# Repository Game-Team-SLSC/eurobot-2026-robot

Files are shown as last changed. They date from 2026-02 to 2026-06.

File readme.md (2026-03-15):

# Game Team's Eurobot 2026 Robot

## Hardware

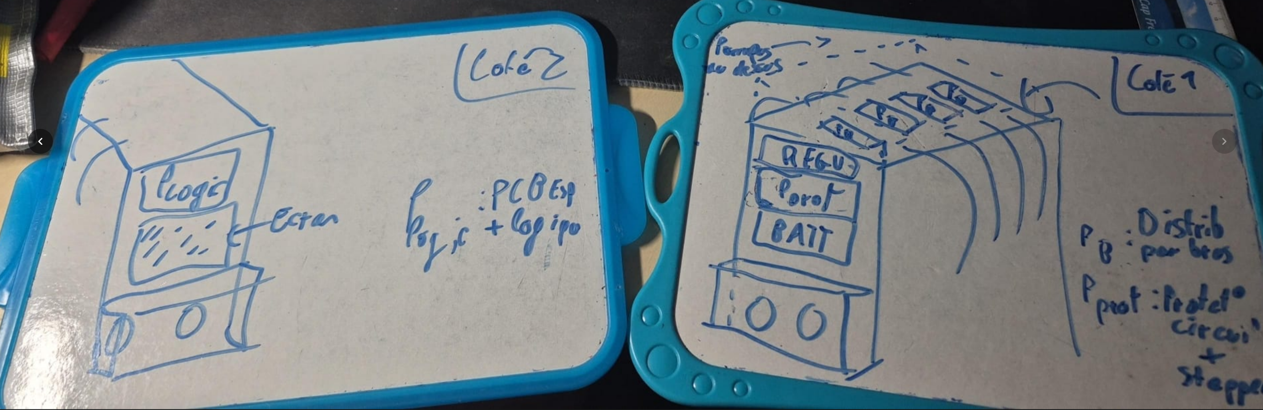
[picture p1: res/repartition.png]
Hardware


### Architecture Diagram

```mermaid
graph LR
    %% SOURCES EXTERNES
    Batt((Batterie LiPo 4S))
    BAU[Bouton AU]

    %% PCB 1: LOGIC BOARD
    subgraph LB [Logic Board]
        direction TB
        MCU[ESP32-S3]
        Radio[Module Radio]
        Screen[Écran LCD]
        MCU --- Radio
        MCU --- Screen
    end

    %% PCB 2: POWER BOARD
    subgraph PB [Power Board]
        direction TB
        Prot[Protection Batterie]
        subgraph Drivers [Drivers Steppers]
            D_4x[4x Drivers]
        end
    end

    %% PCB 3: SERVO REGULATORS (Considéré comme un bloc PCB)
    subgraph Regs [Regulators Board]
        direction TB
        SR[2x 200W Servos]
        PR[1x 200W Pump Reg]
        Fan[1x Ventilateur]
    end

    %% PCB 4: ARM BOARD
    subgraph AB [Arm Board]
        direction TB
        PCA[3x PCA9685]
        Mos[4x MOSFET Pumps]
    end

    %% MATÉRIEL PHYSIQUE (Hors PCB)
    subgraph Mecanique [Éléments Mécaniques]
        Mots[4x Steppers]
        CN[Chasse-Neige]
        Bras[Bras & Pompes]
    end

    %% CONNEXIONS INTER-PCB (Puissance)
    Batt == "16.8V" ==> PB
    PB == "16.8V" ==> LB
    PB == "16.8V" ==> Regs
    Regs == "7V / 12V" ==> AB
    BAU -.-> PB
    AB -- PWM -->Regs

    %% CONNEXIONS INTER-PCB (Signaux)
    LB -- "SPI" --> PB
    LB -- "I2C Main" --> AB
    PB -- "Télémétrie" --> LB

    %% CONNEXIONS PCB VERS MÉCANIQUE
    PB == "Phases" ==> Mots
    AB -- "PWM" --> CN
    AB -- "Faisceau" --> Bras

    %% STYLES
    style LB fill:#f3e5f5,stroke:#7b1fa2,stroke-width:2px
    style PB fill:#fff9c4,stroke:#fbc02d,stroke-width:2px
    style Regs fill:#e1f5fe,stroke:#0288d1,stroke-width:2px
    style AB fill:#e8f5e9,stroke:#2e7d32,stroke-width:2px
```

### Power PCB

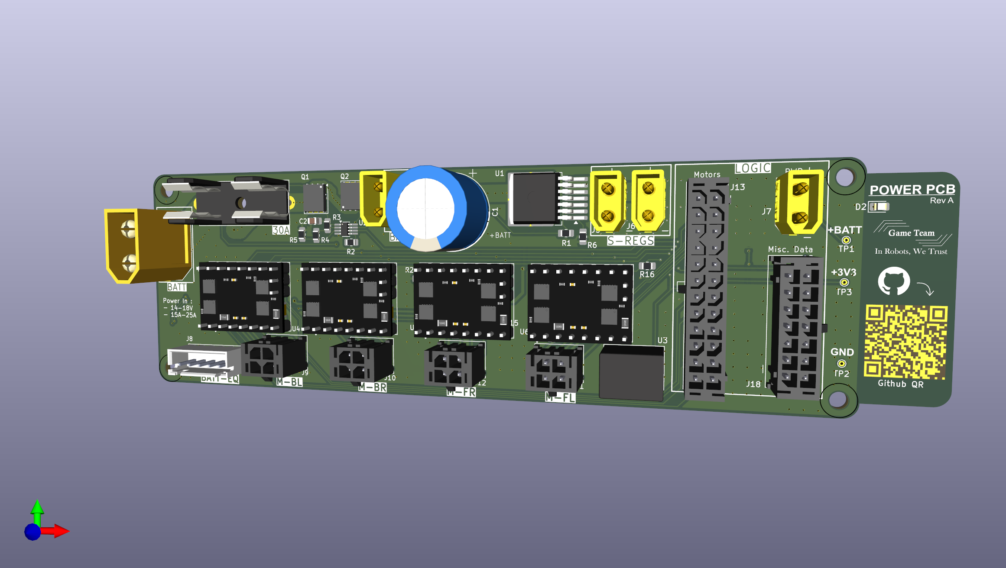
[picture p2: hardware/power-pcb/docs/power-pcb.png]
Power PCB


### Kinetic PCB

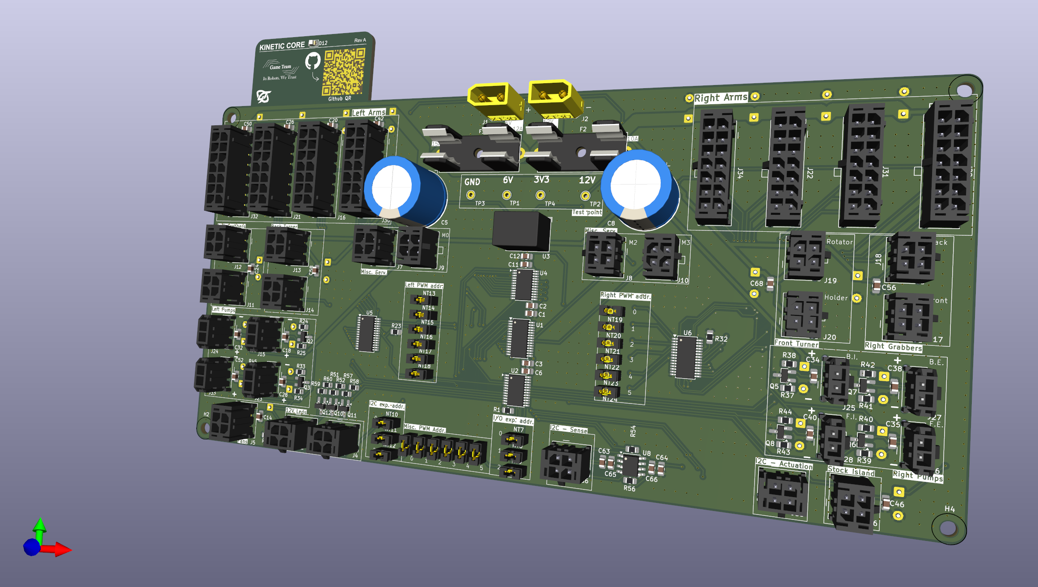
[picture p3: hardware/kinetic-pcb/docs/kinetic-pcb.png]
Kinetic PCB


### Logic PCB

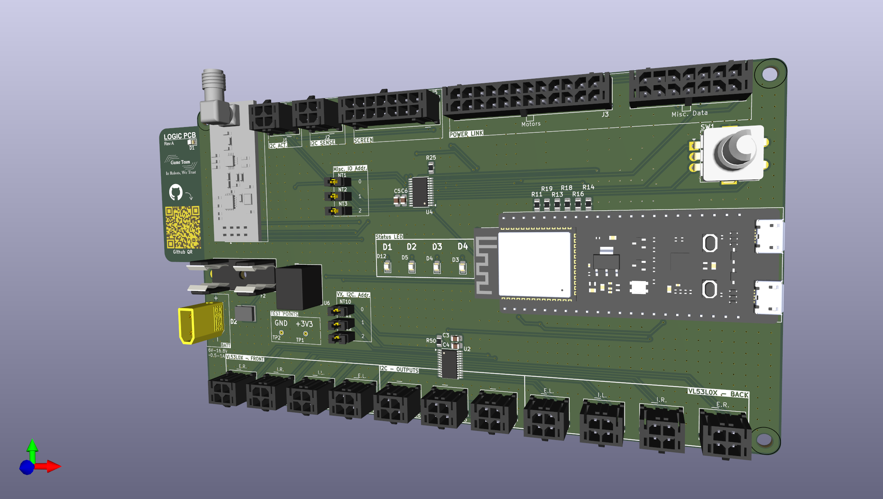
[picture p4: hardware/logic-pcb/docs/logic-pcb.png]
Logic PCB


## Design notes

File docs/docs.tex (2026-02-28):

\documentclass{article}
\usepackage{amsmath}
\title{Eurobot 2026 Robot PCB Documentation}
\author{Game Team SLSC}
\date{\today}

\begin{document}
\maketitle

\section{Introduction}
This document contains the documentation for the Eurobot 2026 Robot PCB.

We selected 0805 package resistors as minimal case as they represent the minimum comfortable size for hand soldering. \\
Pulldown/up resistors will not be considered in the power dissipation calculations as their values are greater than $4.7k\Omega$, resulting in negligible power dissipation.

\section{Batt Input}
\section{Batt Input Analysis}

\subsection{MOSFET (Q2: IRF4905)}
The IRF4905 acts as a high-side P-channel switch for reverse polarity protection. Its key specifications are:
\begin{itemize}
    \item Max continuous drain current: $I_{D} = -74\text{A}$ (at $T_C = 25^\circ\text{C}$)
    \item Max power dissipation: $P_{D} = 150\text{W}$ (at $T_C = 25^\circ\text{C}$)
    \item $R_{DS(on)}$ (static): $0.02\Omega$ (at $V_{GS} = -10\text{V}$, $I_{D} = -19\text{A}$)
    \item Max Gate-Source Voltage: $V_{GS(max)} = \pm 20\text{V}$
\end{itemize}

The maximum current drawn by the robot is $I_{max} = 15\text{A}$. 
At $25^\circ\text{C}$ junction temperature, the power dissipation is:
$$P = R_{DS(on)} \cdot I^2 = 0.02\Omega \cdot (15\text{A})^2 = 4.5\text{W}$$

\textbf{Thermal Correction:} In real-world conditions, $R_{DS(on)}$ increases with temperature. At $T_J = 125^\circ\text{C}$, $R_{DS(on)}$ is approximately $1.6 \times$ its nominal value ($\approx 0.032\Omega$), leading to $P \approx 7.2\text{W}$. 
With a $R_{\theta JA}$ of $62^\circ\text{C/W}$ for a TO-220 package without a heatsink, the temperature rise would exceed $400^\circ\text{C}$. Therefore, a \textbf{heatsink} or significant copper pouring on the PCB is mandatory.

\subsection{Zener Diode (D2: 1N4744A)}
The 1N4744A is used to protect the \textbf{Gate-Source junction} of the MOSFET, not the downstream load. 
\begin{itemize}
    \item Zener voltage: $V_{Z} = 15\text{V}$ (at $I_{Z} = 18\text{mA}$)
    \item Max power dissipation: $P_{Z} = 1\text{W}$
    \item Current limit: $I_{Zmax} = \frac{P_{Z}}{V_{Z}} = \frac{1\text{W}}{15\text{V}} = 66.7\text{mA}$
\end{itemize}

In this circuit, the current through the Zener is limited by $R2$ ($10\text{k}\Omega$). If the battery voltage is $24\text{V}$:
$$I_{Z} = \frac{V_{BATT} - V_{Z}}{R2} = \frac{24\text{V} - 15\text{V}}{10,000\Omega} = 0.9\text{mA}$$
This is well within the $66.7\text{mA}$ limit. The Zener ensures $V_{GS}$ never exceeds $15\text{V}$, staying safely below the $20\text{V}$ limit of the IRF4905.

\subsection{TVS Diode (D3: SMBJ18A)}
The SMBJ18A provides transient voltage suppression for the \textbf{entire system}.
\begin{itemize}
    \item Reverse Standoff Voltage: $V_{RWM} = 18\text{V}$ (The diode does not conduct at normal $12\text{V}$ battery levels).
    \item Peak Pulse Power: $P_{PP} = 600\text{W}$ (for $10/1000\mu\text{s}$ pulses).
\end{itemize}
This component is critical for absorbing inductive spikes from motors or "hot-plugging" the battery, preventing the destruction of downstream regulators.

\subsection{Power Dissipation Summary}

\begin{itemize}
    \item \textbf{MOSFET (Q2):} Dissipates $\approx 4.5\text{W}$ at $15\text{A}$ ($25^\circ\text{C}$). Due to $R_{DS(on)}$ increase at high temperature, real dissipation can reach $\approx 7.2\text{W}$. \textbf{A heatsink is mandatory.}
    
    \item \textbf{Zener Diode (D2):} With $R2 = 10\text{k}\Omega$ and $V_{batt} = 24\text{V}$, the current $I_Z$ is only $0.9\text{mA}$. 
    $$P_{D2} = 15\text{V} \cdot 0.9\text{mA} = 13.5\text{mW}$$
    This is far below the $1\text{W}$ rating. Power dissipation is \textbf{negligible}.

    \item \textbf{TVS Diode (D3):} Dissipates \textbf{0W} during normal operation ($V_{batt} < 18\text{V}$). It is rated for $600\text{W}$ peak pulse power to handle millisecond transients.
\end{itemize}

\section{Balancing check}
The PCB is intended to monitor the state of each battery cell and ensure they are balanced.
If a cell voltage exceeds or drops below a certain threshold, a warning will be triggered.

\subsection{Cell 1}
\subsubsection{Specifications}
\begin{itemize}
\item Series voltage: $V_{in} = V_{cell1} = 4.2V (\max) / 3.5V (\min)$
\item $V_{out} = 2.5V (\max)$
\item $I = 100\mu A$ (target current through the voltage divider)
\end{itemize}
The input impedance of the ESP32 ADC is sufficiently high ($>1M\Omega$) to neglect the loading effect on the voltage divider.

\subsubsection{Divider calculation}
Using a voltage divider:
$$V_{out} = V_{in} \cdot \frac{R_2}{R_1 + R_2}$$
$$R_{total} = R_1 + R_2 = \frac{V_{in}}{I} = \frac{4.2V}{100\mu A} = 42k\Omega$$
$$R_2 = \frac{V_{out}}{V_{in}} \cdot R_{total} = \frac{2.5V}{4.2V} \cdot 42k\Omega = 25k\Omega$$
$$R_1 = R_{total} - R_2 = 42k - 25k = 17k\Omega$$

\subsubsection{Standard values (E96 1\%)}
\begin{itemize}
\item $R_1 = 16.9k\Omega$
\item $R_2 = 24.9k\Omega$
\end{itemize}

\subsubsection{Min/Max check}
At $V_{in} = 4.2V$:
$$V_{out} = 4.2V \cdot \frac{24.9k}{16.9k + 24.9k} = 2.50V$$
At $V_{in} = 3.5V$:
$$V_{out} = 3.5V \cdot \frac{24.9k}{16.9k + 24.9k} = 2.08V$$

\subsubsection{Tolerance (1\%)}
At $V_{in} = 4.2V$, worst case scenarios:
\begin{itemize}
    \item Max Output: $R_1 (-1\%), R_2 (+1\%) \rightarrow V_{out} = 2.52V$
    \item Min Output: $R_1 (+1\%), R_2 (-1\%) \rightarrow V_{out} = 2.47V$
\end{itemize}
The output remains safely within the ESP32 ADC linear range.

\subsection{Cell 2}
\subsubsection{Specifications}
\begin{itemize}
\item Series voltage: $V_{in} = V_{cell1} + V_{cell2} = 8.4V (\max) / 7.0V (\min)$
\item $V_{out} = 2.5V (\max)$
\item $I = 100\mu A$ (target current)
\end{itemize}

\subsubsection{Divider calculation}
$$R_{total} = \frac{8.4V}{100\mu A} = 84k\Omega$$
$$R_2 = \frac{2.5V}{8.4V} \cdot 84k\Omega = 25k\Omega$$
$$R_1 = 84k - 25k = 59k\Omega$$

\subsubsection{Standard values (E96 1\%)}
\begin{itemize}
\item $R_1 = 59.0k\Omega$
\item $R_2 = 24.9k\Omega$
\end{itemize}

\subsubsection{Min/Max check}
At $V_{in} = 8.4V$: $V_{out} = 2.49V$ \\
At $V_{in} = 7.0V$: $V_{out} = 2.07V$

\subsubsection{Tolerance check}
Max $V_{out}$ (with $1\%$ tolerance): $2.53V$. Acceptable.

\subsection{Cell 3}
\subsubsection{Specifications}
\begin{itemize}
\item Series voltage: $V_{in} = \sum_{i=1}^{3} V_{celli} = 12.6V (\max) / 10.5V (\min)$
\item $V_{out} = 2.5V (\max)$
\end{itemize}

\subsubsection{Divider calculation}
$$R_{total} = \frac{12.6V}{100\mu A} = 126k\Omega$$
$$R_2 = \frac{2.5V}{12.6V} \cdot 126k\Omega = 25k\Omega$$
$$R_1 = 126k - 25k = 101k\Omega$$

\subsubsection{Standard values (E96 1\%)}
\begin{itemize}
\item $R_1 = 100k\Omega$
\item $R_2 = 24.9k\Omega$
\end{itemize}

\subsubsection{Min/Max check}
At $V_{in} = 12.6V$: $V_{out} = 2.51V$ \\
At $V_{in} = 10.5V$: $V_{out} = 2.09V$

\subsubsection{Tolerance check}
Max $V_{out}$ (with $1\%$ tolerance): $2.55V$. Acceptable.

\subsection{Cell 4}
\subsubsection{Specifications}
\begin{itemize}
\item Series voltage: $V_{in} = \sum_{i=1}^{4} V_{celli} = 16.8V (\max) / 14.0V (\min)$
\item $V_{out} = 2.5V (\max)$
\end{itemize}

\subsubsection{Divider calculation}
$$R_{total} = \frac{16.8V}{100\mu A} = 168k\Omega$$
$$R_2 = \frac{2.5V}{16.8V} \cdot 168k\Omega = 25k\Omega$$
$$R_1 = 168k - 25k = 143k\Omega$$

\subsubsection{Standard values (E96 1\%)}
\begin{itemize}
\item $R_1 = 143k\Omega$
\item $R_2 = 24.9k\Omega$
\end{itemize}

\subsubsection{Min/Max check}
At $V_{in} = 16.8V$: $V_{out} = 2.49V$ \\
At $V_{in} = 14.0V$: $V_{out} = 2.08V$

\subsubsection{Tolerance check}
Max $V_{out}$ (with $1\%$ tolerance): $2.53V$. Acceptable.

\end{document}

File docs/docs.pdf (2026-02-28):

# Eurobot 2026 Robot PCB Documentation

Game Team SLSC

January 27, 2026

## 1 Introduction

This document contains the documentation for the Eurobot 2026 Robot PCB. We selected 0805 package resistors as minimal case as they represent the minimum comfortable size for hand soldering.
Pulldown/up resistors will not be considered in the power dissipation calculations as their values are greater than 4.7kΩ, resulting in negligible power dissipation.

## 2 Batt Input

## 3 Batt Input Analysis

### 3.1 MOSFET (Q2: IRF4905)

The IRF4905 acts as a high-side P-channel switch for reverse polarity protection. Its key specifications are:

| Max continuous drain current: ID = −74A (at TC = 25◦C)
| Max power dissipation: PD = 150W (at TC = 25◦C)
| RDS(on) (static): 0.02Ω (at VGS = −10V, ID = −19A)
| Max Gate-Source Voltage: VGS(max) = ±20V

The maximum current drawn by the robot is Imax = 15A. At 25◦C junction temperature, the power dissipation is:

| P = RDS(on) · I 2 = 0.02Ω · (15A)² = 4.5W

Thermal Correction: In real-world conditions, RDS(on)
| increases with
temperature. At TJ = 125◦C, RDS(on)
| is approximately 1.6× its nominal value
(≈ 0.032Ω), leading to P ≈ 7.2W. With a RθJA of 62◦C/W for a TO-220 package without a heatsink, the temperature rise would exceed 400◦C. Therefore, a heatsink or significant copper pouring on the PCB is mandatory.
| 1

### 3.2 Zener Diode (D2: 1N4744A)

The 1N4744A is used to protect the Gate-Source junction of the MOSFET, not the downstream load.

| Zener voltage: VZ = 15V (at IZ = 18mA)
| Max power dissipation: PZ = 1W
| Current limit: IZmax = PZ VZ = 1W 15V = 66.7mA

In this circuit, the current through the Zener is limited by R2 (10kΩ). If the battery voltage is 24V:

| IZ = VBAT T − VZ R2 = 24V − 15V 10, 000Ω = 0.9mA

This is well within the 66.7mA limit. The Zener ensures VGS never exceeds 15V, staying safely below the 20V limit of the IRF4905.

### 3.3 TVS Diode (D3: SMBJ18A)

The SMBJ18A provides transient voltage suppression for the entire system.

| Reverse Standoff Voltage: VRWM = 18V (The diode does not conduct at normal 12V battery levels).
| Peak Pulse Power: PP P = 600W (for 10/1000µs pulses).

This component is critical for absorbing inductive spikes from motors or ”hotplugging” the battery, preventing the destruction of downstream regulators.

### 3.4 Power Dissipation Summary

| MOSFET (Q2): Dissipates ≈ 4.5W at 15A (25◦C). Due to RDS(on) increase at high temperature, real dissipation can reach ≈ 7.2W. A heatsink is mandatory.
| Zener Diode (D2): With R2 = 10kΩ and Vbatt = 24V, the current IZ is only 0.9mA. PD2 = 15V · 0.9mA = 13.5mW This is far below the 1W rating. Power dissipation is negligible.
| TVS Diode (D3): Dissipates 0W during normal operation (Vbatt < 18V). It is rated for 600W peak pulse power to handle millisecond tran- sients.

2

## 4 Balancing check

The PCB is intended to monitor the state of each battery cell and ensure they are balanced. If a cell voltage exceeds or drops below a certain threshold, a warning will be triggered.

### 4.1 Cell 1

### 4.1.1 Specifications

| Series voltage: Vin = Vcell1 = 4.2V (max)/3.5V (min)
| Vout = 2.5V (max)
| I = 100µA (target current through the voltage divider)

The input impedance of the ESP32 ADC is sufficiently high (> 1MΩ) to neglect the loading effect on the voltage divider.

### 4.1.2 Divider calculation

Using a voltage divider:
| Vout = Vin · R2 R1 + R2

Rtotal = R1 + R2 =

Vin
I

=

4.2V
100µA = 42kΩ

R2 =

Vout

Vin

- Rtotal =

2.5V
4.2V
- 42kΩ = 25kΩ

R1 = Rtotal − R2 = 42k − 25k = 17kΩ

### 4.1.3 Standard values (E96 1%)

| R1 = 16.9kΩ
| R2 = 24.9kΩ

### 4.1.4 Min/Max check

At Vin = 4.2V :

Vout = 4.2V ·

24.9k
16.9k + 24.9k

= 2.50V

At Vin = 3.5V :

Vout = 3.5V ·

24.9k
16.9k + 24.9k

= 2.08V

3

### 4.1.5 Tolerance (1%)

At Vin = 4.2V , worst case scenarios:

| Max Output: R1(−1%), R2(+1%) → Vout = 2.52V
| Min Output: R1(+1%), R2(−1%) → Vout = 2.47V

The output remains safely within the ESP32 ADC linear range.

### 4.2 Cell 2

### 4.2.1 Specifications

| Series voltage: Vin = Vcell1 + Vcell2 = 8.4V (max)/7.0V (min)
| Vout = 2.5V (max)
| I = 100µA (target current)

### 4.2.2 Divider calculation

| Rtotal = 8.4V 100µA = 84kΩ
| R2 = 2.5V 8.4V · 84kΩ = 25kΩ
| R1 = 84k − 25k = 59kΩ

### 4.2.3 Standard values (E96 1%)

| R1 = 59.0kΩ
| R2 = 24.9kΩ

### 4.2.4 Min/Max check

At Vin = 8.4V : Vout = 2.49V At Vin = 7.0V : Vout = 2.07V

### 4.2.5 Tolerance check

Max Vout (with 1% tolerance): 2.53V . Acceptable.

### 4.3 Cell 3

### 4.3.1 Specifications

Series voltage: Vin =

P3
| i=1 Vcelli = 12.6V (max)/10.5V (min)
| Vout = 2.5V (max)

4

### 4.3.2 Divider calculation

Rtotal =

12.6V
100µA = 126kΩ

R2 =

2.5V
12.6V
- 126kΩ = 25kΩ

R1 = 126k − 25k = 101kΩ

### 4.3.3 Standard values (E96 1%)

| R1 = 100kΩ
| R2 = 24.9kΩ

### 4.3.4 Min/Max check

At Vin = 12.6V : Vout = 2.51V At Vin = 10.5V : Vout = 2.09V

### 4.3.5 Tolerance check

Max Vout (with 1% tolerance): 2.55V . Acceptable.

### 4.4 Cell 4

### 4.4.1 Specifications

Series voltage: Vin =

P4
i=1 Vcelli = 16.8V (max)/14.0V (min)

Vout = 2.5V (max)

### 4.4.2 Divider calculation

Rtotal =

16.8V
100µA = 168kΩ
| R2 =

2.5V
16.8V
- 168kΩ = 25kΩ
| R1 = 168k − 25k = 143kΩ

### 4.4.3 Standard values (E96 1%)

| R1 = 143kΩ
| R2 = 24.9kΩ

### 4.4.4 Min/Max check

At Vin = 16.8V : Vout = 2.49V At Vin = 14.0V : Vout = 2.08V

5

### 4.4.5 Tolerance check

Max Vout (with 1% tolerance): 2.53V . Acceptable.

6

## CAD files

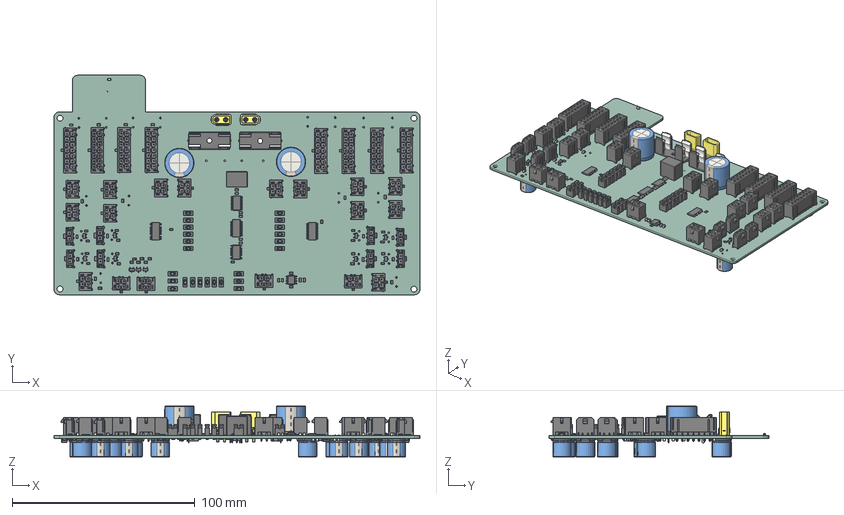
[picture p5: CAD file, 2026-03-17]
hardware/kinetic-pcb/out/kinetic-pcb.step
200.0 x 120.0 x 27.7 mm
Jumper x 24
J_Wurth_WR-MPC3_66200421122 x 18
R_0805_2012Metric x 57
C_0805_2012Metric x 44
J_Wurth_WR-MPC3_66201421122 x 8
TSOT-23 x 12
Fuseholder_Cylinder-5x20mm_Schurter_0031_8201_Horizontal_Open x 2
XT30-M_m.ver x 2
J_Wurth_WR-MPC3_66200211122 x 8
CP_Radial_D16.0mm_P7.50mm x 2
TSSOP-28_4.4x9.7mm_P0.65mm x 3
LED_0805_2012Metric
SOIC-8_3.9x4.9mm_P1.27mm x 2
TSSOP-24_4.4x7.8mm_P0.65mm x 2
Converter_DCDC_RECOM_R-78E-0.5_THT
CP_Radial_D10.0mm_P5.00mm x 22
D_SMA x 9
Pins x 2
kinetic-pcb_PCB

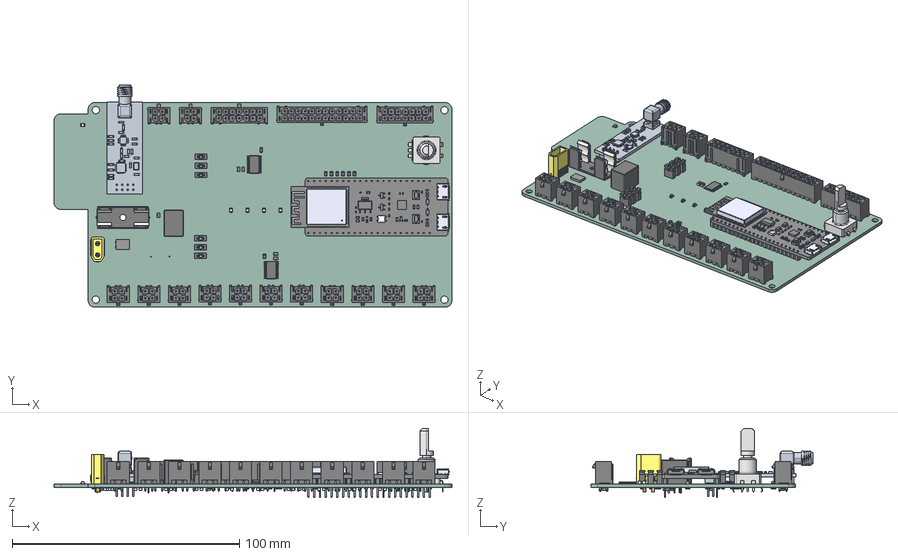
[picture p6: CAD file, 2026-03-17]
hardware/logic-pcb/out/logic-pcb.step
175.0 x 97.8 x 30.5 mm
Jumper x 6
TSSOP-24_4.4x7.8mm_P0.65mm x 2
LED_0805_2012Metric x 5
ESP32-S3-DEVKITC-1-N8R2--3DModel-STEP-56544 (1)
J_Wurth_WR-MPC3_66200421122 x 13
Converter_DCDC_RECOM_R-78E-0.5_THT
R_0805_2012Metric x 41
J_Wurth_WR-MPC3_66201421122 x 2
Encoder EC11E Alps
C_0805_2012Metric x 34
RF TransmiterReciever
J_Wurth_WR-MPC3_66202421122
Pins
Fuseholder_Cylinder-5x20mm_Schurter_0031_8201_Horizontal_Open
XT30-M_m.ver
L_0805_2012Metric x 2
logic-pcb_PCB

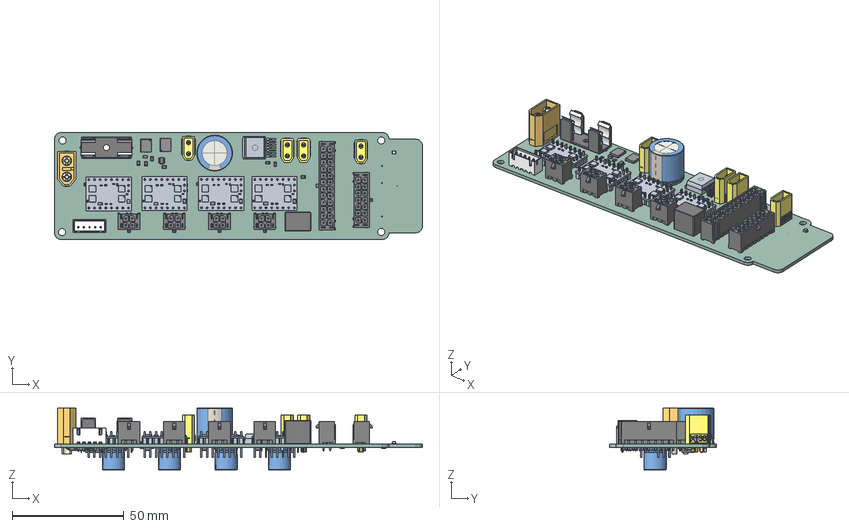
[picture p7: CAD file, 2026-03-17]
hardware/power-pcb/out/power-pcb.step
165.0 x 48.0 x 27.7 mm
power-pcb 1.1.1
R_0805_2012Metric x 29
BxB-XH-A_05
Fuseholder_Cylinder-5x20mm_Schurter_0031_8201_Horizontal_Open
LED_0805_2012Metric
C_0805_2012Metric x 17
XT30-M_m.ver x 4
SI7288DP-T1-GE3--3DModel-STEP-56544 x 2
CP_Radial_D16.0mm_P7.50mm
TSOT-23-8
J_Wurth_WR-MPC3_66200421122 x 4
Converter_DCDC_RECOM_R-78E-0.5_THT
AMASS_XT60-M_1x02_P7.2mm_Vertical
power-pcb 1.29.1 x 4
power-pcb 1.29.2 x 4
power-pcb 1.29.3 x 4
power-pcb 1.29.4 x 4
power-pcb 1.29.5 x 4
power-pcb 1.29.6 x 4
power-pcb 1.29.7 x 4
power-pcb 1.29.8 x 4
power-pcb 1.29.9 x 4
power-pcb 1.29.10 x 4
power-pcb 1.29.11 x 4
power-pcb 1.29.12 x 4
power-pcb 1.29.13 x 4
power-pcb 1.29.14 x 4
power-pcb 1.29.15 x 4
power-pcb 1.29.16 x 4
power-pcb 1.29.17 x 4
power-pcb 1.29.18 x 4
power-pcb 1.29.19 x 4
power-pcb 1.29.20 x 4
power-pcb 1.29.21 x 4
power-pcb 1.29.22 x 4
power-pcb 1.29.23 x 4
power-pcb 1.29.24 x 4
power-pcb 1.29.25 x 4
power-pcb 1.29.26 x 4
power-pcb 1.29.27 x 4
power-pcb 1.29.28 x 4
power-pcb 1.29.29 x 4
power-pcb 1.29.30 x 4
power-pcb 1.29.31 x 4
power-pcb 1.29.32 x 4
power-pcb 1.29.33 x 4
power-pcb 1.29.34 x 4
J_Wurth_WR-MPC3_66202421122
J_Wurth_WR-MPC3_66201421122
TSSOP-10_3x3mm_P0.5mm
D_SMC
CP_Radial_D10.0mm_P5.00mm x 4
L_0805_2012Metric
power-pcb_PCB

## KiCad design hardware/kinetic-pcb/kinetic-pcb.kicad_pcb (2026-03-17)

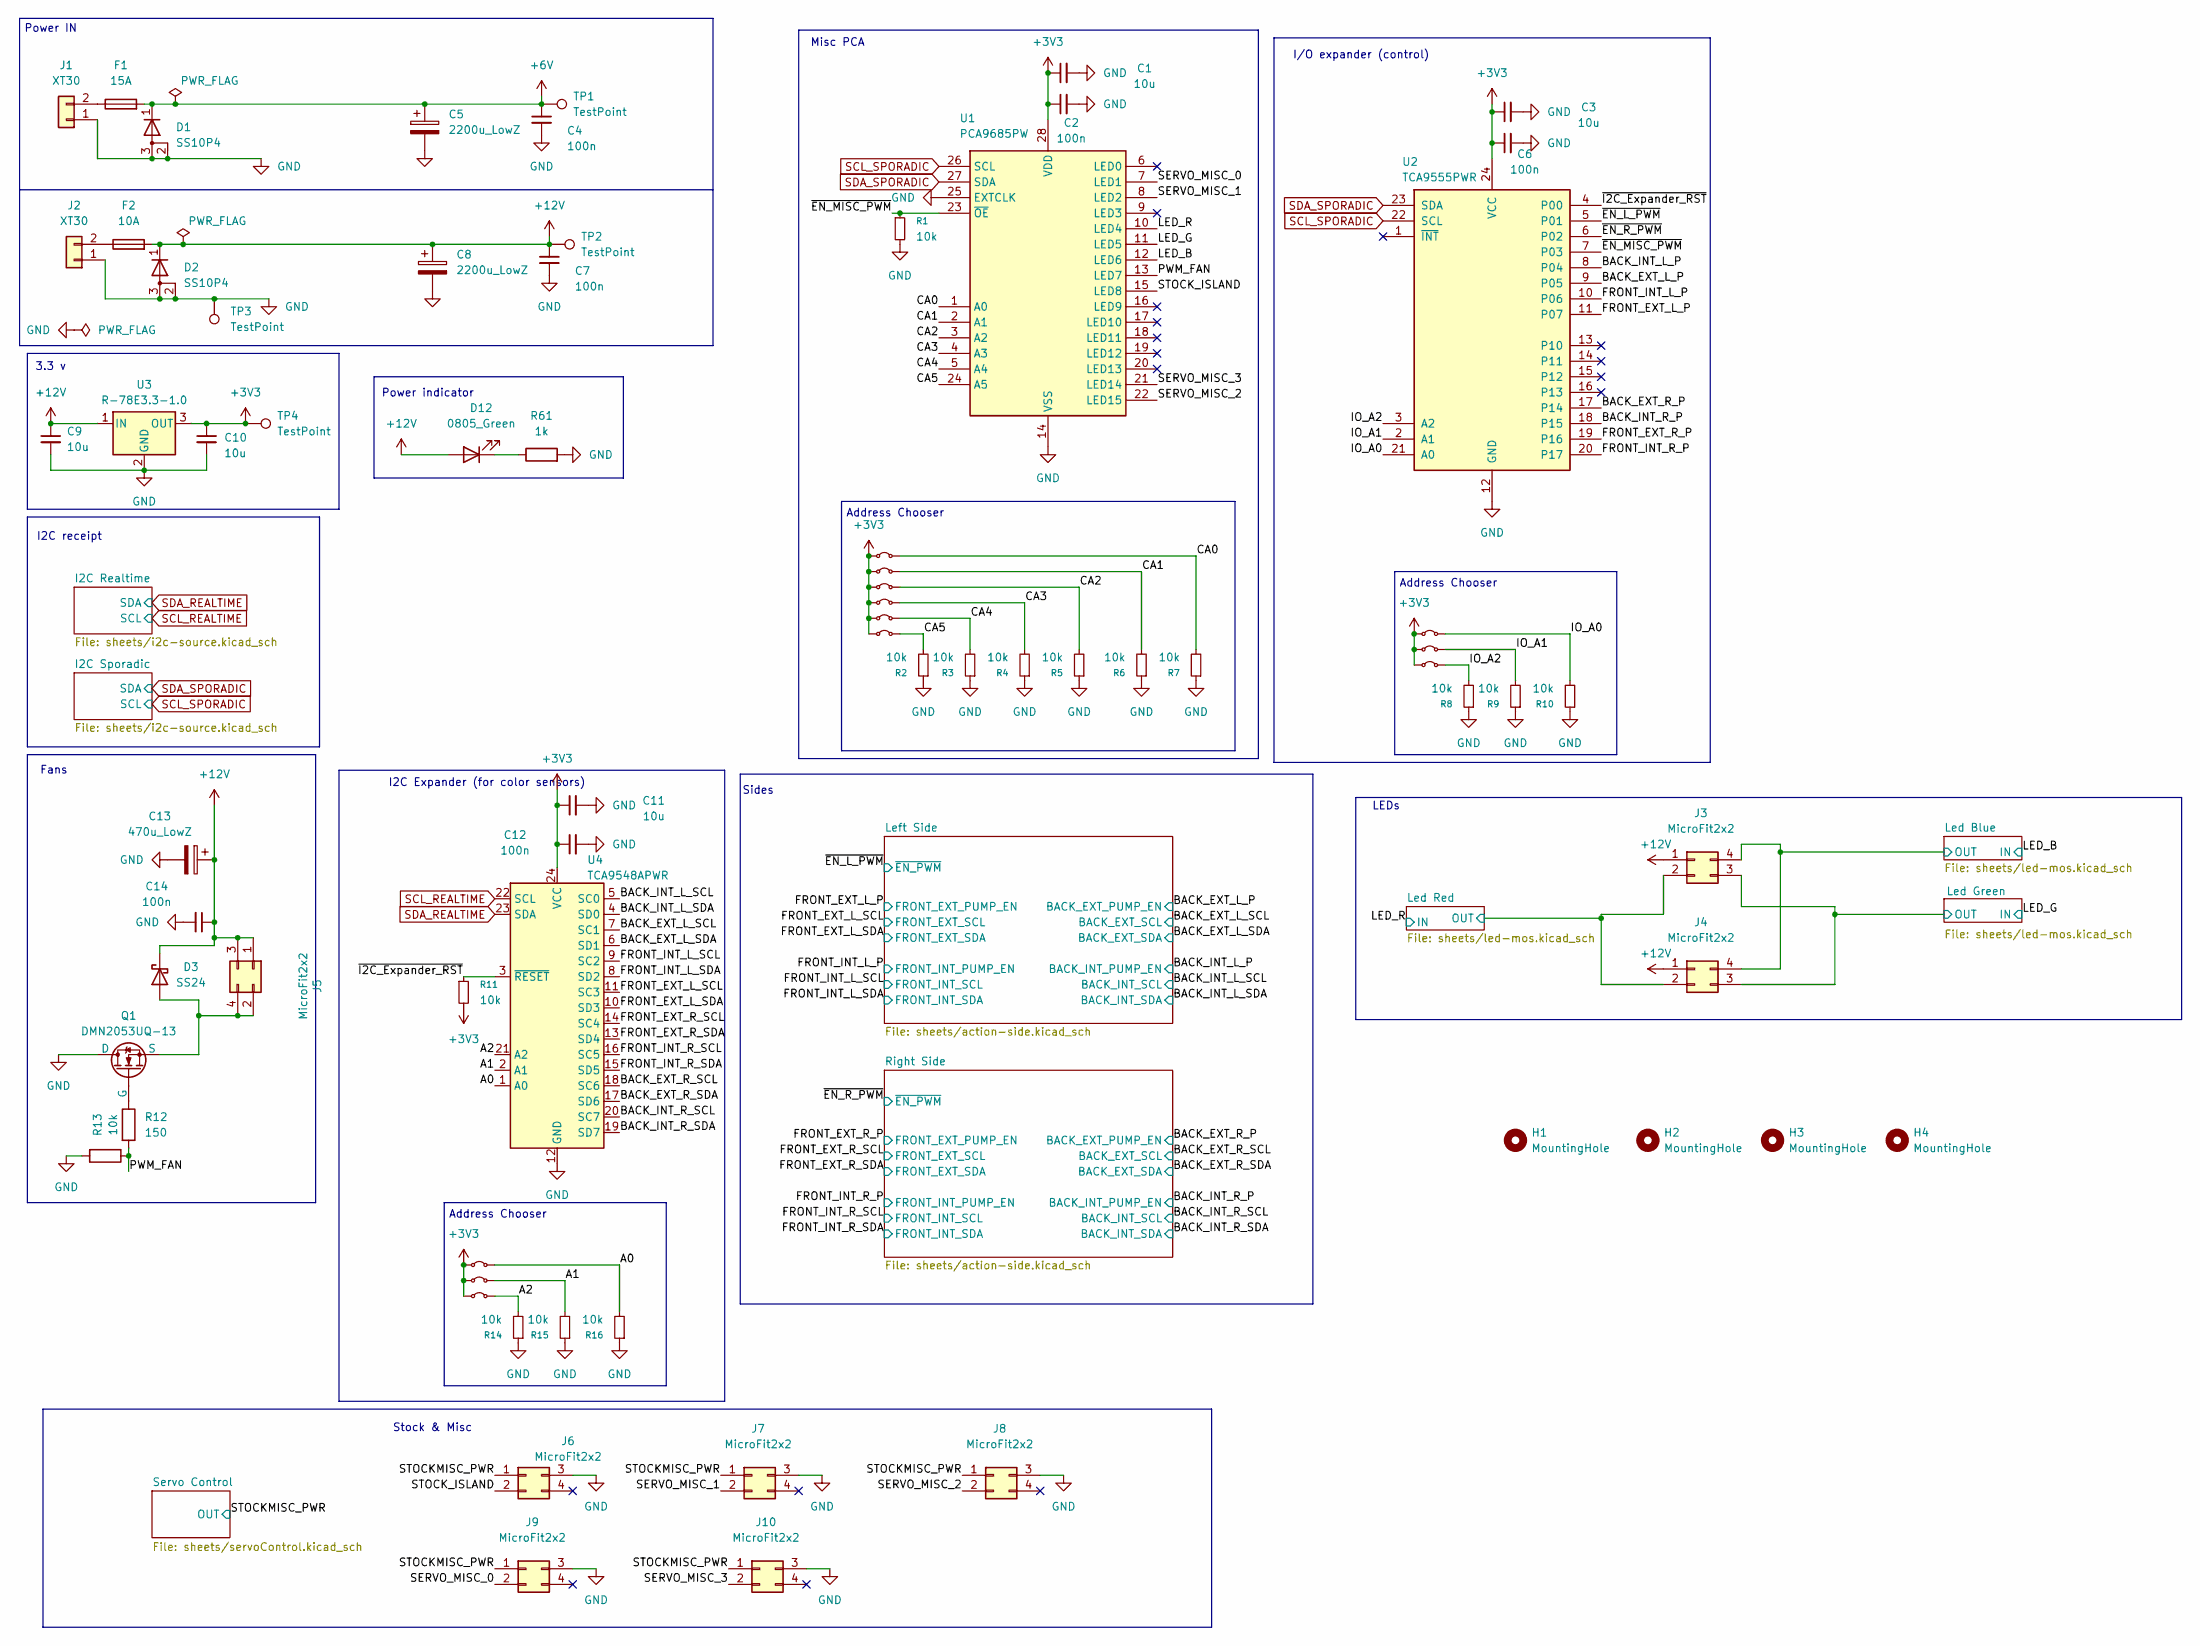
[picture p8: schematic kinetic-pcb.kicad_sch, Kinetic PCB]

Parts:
C1, C3, C9, C10, C11: 10u; C_0805_2012Metric_Pad1.18x1.45mm_HandSolder; MPN CL21A106KBYQNNE
C2, C4, C6, C7, C12, C14: 100n; C_0805_2012Metric_Pad1.18x1.45mm_HandSolder; MPN CL21B104KBCNNND
C5, C8: 2200u_LowZ; CP_Radial_D16.0mm_P7.50mm; MPN EEUFR1V222
C13: 470u_LowZ; CP_Radial_D10.0mm_P5.00mm; MPN EEU-FR1E471
D1, D2: SS10P4; SS10P4M387A; MPN SS10P4-M3/87A
D3: SS24; D_SMA_Handsoldering; MPN SS24S-E3/5AT
D12: 0805_Green; LED_0805_2012Metric_Pad1.15x1.40mm_HandSolder; MPN APA2106ZGCK
F1: 15A; Fuseholder_Cylinder-5x20mm_Schurter_0031_8201_Horizontal_Op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
F2: 10A; Fuseholder_Cylinder-5x20mm_Schurter_0031_8201_Horizontal_Op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
H1, H2, H3, H4: MountingHole; MountingHole_3.2mm_M3
J1, J2: XT30; AMASS_XT30U-M_1x02_P5.0mm_Vertical
J3, J4, J5, J6, J7, J8, J9, J10: MicroFit2x2; J_Wurth_WR-MPC3_66200421122; MPN 66200421122
NT1, NT2, NT3, NT4, NT5, NT6, NT7, NT8, NT9, NT10, NT11, NT12: Jumper_2_Bridged; TestPoint_2Pads_Pitch2.54mm_Drill0.8mm; MPN M7582-46
Q1: DMN2053UQ-13; SOT-23_Handsoldering-DMN2053UQ; MPN DMN2053UQ-13
R1, R2, R3, R4, R5, R6, R7, R8, R9, R10, R11, R13, R14, R15, R16: 10k; R_0805_2012Metric_Pad1.20x1.40mm_HandSolder; MPN CRCW080510K0FKEA
R12: 150; R_0805_2012Metric_Pad1.20x1.40mm_HandSolder; MPN CRCW0805150RFKEA
R61: 1k; R_0805_2012Metric_Pad1.20x1.40mm_HandSolder; MPN CRCW08051K00FKEA
TP1, TP2, TP3, TP4: TestPoint; TestPoint_THTPad_D2.0mm_Drill1.0mm
U1: PCA9685PW; TSSOP-28_4.4x9.7mm_P0.65mm; MPN PCA9685PW,118
U2: TCA9555PWR; TSSOP-24_4.4x7.8mm_P0.65mm; MPN TCA9555PWR
U3: R-78E3.3-1.0; Converter_DCDC_RECOM_R-78E-0.5_THT; MPN R-78E3.3-1.0
U4: TCA9548APWR; TSSOP-24_4.4x7.8mm_P0.65mm; MPN TCA9548APWR

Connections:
+3V3: C1.1, C2.1, C3.1, C6.1, C10.1, C11.1, C12.1, NT1.1 (A), NT2.1 (A), NT3.1 (A), NT4.1 (A), NT5.1 (A), NT6.1 (A), NT7.1 (A), NT8.1 (A), NT9.1 (A), NT10.1 (A), NT11.1 (A), NT12.1 (A), R11.2, TP4.1, U1.28 (VDD), U2.24 (VCC), U3.3 (OUT), U4.24 (VCC); also elsewhere on the board
+6V: C4.1, C5.1, D1.1 (K), F1.2, J6.1, J7.1, J8.1, J9.1, J10.1, TP1.1; also elsewhere on the board
+12V: C7.1, C8.1, C9.1, C13.1, C14.1, D2.1 (K), D3.1 (K), D12.2 (A), F2.2, J3.1, J4.1, J5.1, J5.3, TP2.1, U3.1 (IN); also elsewhere on the board
/A0: NT10.2 (B), R16.2, U4.1 (A0)
/A1: NT11.2 (B), R15.2, U4.2 (A1)
/A2: NT12.2 (B), R14.2, U4.21 (A2)
/BACK_EXT_L_P: U2.9 (P05); also elsewhere on the board
/BACK_EXT_L_SCL: U4.7 (SC1); also elsewhere on the board
/BACK_EXT_L_SDA: U4.6 (SD1); also elsewhere on the board
/BACK_EXT_R_P: U2.17 (P14); also elsewhere on the board
/BACK_EXT_R_SCL: U4.18 (SC6); also elsewhere on the board
/BACK_EXT_R_SDA: U4.17 (SD6); also elsewhere on the board
/BACK_INT_L_P: U2.8 (P04); also elsewhere on the board
/BACK_INT_L_SCL: U4.5 (SC0); also elsewhere on the board
/BACK_INT_L_SDA: U4.4 (SD0); also elsewhere on the board
/BACK_INT_R_P: U2.18 (P15); also elsewhere on the board
/BACK_INT_R_SCL: U4.20 (SC7); also elsewhere on the board
/BACK_INT_R_SDA: U4.19 (SD7); also elsewhere on the board
/CA0: NT1.2 (B), R7.2, U1.1 (A0)
/CA1: NT2.2 (B), R6.2, U1.2 (A1)
/CA2: NT3.2 (B), R5.2, U1.3 (A2)
/CA3: NT4.2 (B), R4.2, U1.4 (A3)
/CA4: NT5.2 (B), R3.2, U1.5 (A4)
/CA5: NT6.2 (B), R2.2, U1.24 (A5)
/FRONT_EXT_L_P: U2.11 (P07); also elsewhere on the board
/FRONT_EXT_L_SCL: U4.11 (SC3); also elsewhere on the board
/FRONT_EXT_L_SDA: U4.10 (SD3); also elsewhere on the board
/FRONT_EXT_R_P: U2.19 (P16); also elsewhere on the board
/FRONT_EXT_R_SCL: U4.14 (SC4); also elsewhere on the board
/FRONT_EXT_R_SDA: U4.13 (SD4); also elsewhere on the board
/FRONT_INT_L_P: U2.10 (P06); also elsewhere on the board
/FRONT_INT_L_SCL: U4.9 (SC2); also elsewhere on the board
/FRONT_INT_L_SDA: U4.8 (SD2); also elsewhere on the board
/FRONT_INT_R_P: U2.20 (P17); also elsewhere on the board
/FRONT_INT_R_SCL: U4.16 (SC5); also elsewhere on the board
/FRONT_INT_R_SDA: U4.15 (SD5); also elsewhere on the board
/IO_A0: NT7.2 (B), R10.2, U2.21 (A0)
/IO_A1: NT8.2 (B), R9.2, U2.2 (A1)
/IO_A2: NT9.2 (B), R8.2, U2.3 (A2)
/LED_B: U1.12 (LED6); also elsewhere on the board
/LED_G: U1.11 (LED5); also elsewhere on the board
/LED_R: U1.10 (LED4); also elsewhere on the board
/Led Blue/OUT: J3.4, J4.4; also elsewhere on the board
/Led Green/OUT: J3.3, J4.3; also elsewhere on the board
/Led Red/OUT: J3.2, J4.2; also elsewhere on the board
/PWM_FAN: R12.2, R13.1, U1.13 (LED7)
/SERVO_MISC_0: J9.2, U1.7 (LED1)
/SERVO_MISC_1: J7.2, U1.8 (LED2)
/SERVO_MISC_2: J8.2, U1.22 (LED15)
/SERVO_MISC_3: J10.2, U1.21 (LED14)
/STOCK_ISLAND: J6.2, U1.15 (LED8)
/~EN_L_PWM: U2.5 (P01); also elsewhere on the board
/~EN_MISC_PWM: R1.1, U1.23 (~OE), U2.7 (P03)
/~EN_R_PWM: U2.6 (P02); also elsewhere on the board
/~I2C_Expander_RST: R11.1, U2.4 (P00), U4.3 (~RESET)
GND: C1.2, C2.2, C3.2, C4.2, C5.2, C6.2, C7.2, C8.2, C9.2, C10.2, C11.2, C12.2, C13.2, C14.2, D1.2 (A), D1.3 (A), D2.2 (A), D2.3 (A), J1.1, J2.1, J6.3, J7.3, J8.3, J9.3, J10.3, Q1.1 (D), R1.2, R2.1, R3.1, R4.1, R5.1, R6.1, R7.1, R8.1, R9.1, R10.1, R13.2, R14.1, R15.1, R16.1, R61.2, TP3.1, U1.14 (VSS), U1.25 (EXTCLK), U2.12 (GND), U3.2 (GND), U4.12 (GND); also elsewhere on the board
unnamed: D3.2 (A), J5.2, J5.4, Q1.3 (S)
unnamed: D12.1 (K), R61.1
unnamed: F1.1, J1.2
unnamed: F2.1, J2.2
unnamed: Q1.2 (G), R12.1
SCL_REALTIME: U4.22 (SCL); also elsewhere on the board
SCL_SPORADIC: U1.26 (SCL), U2.22 (SCL); also elsewhere on the board
SDA_REALTIME: U4.23 (SDA); also elsewhere on the board
SDA_SPORADIC: U1.27 (SDA), U2.23 (SDA); also elsewhere on the board

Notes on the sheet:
Fans
Address Chooser
3.3 v
Sides
I2C Expander (for color sensors)
Stock & Misc
Power IN
Power indicator
I/O expander (control)
LEDs
Misc PCA
I2C receipt

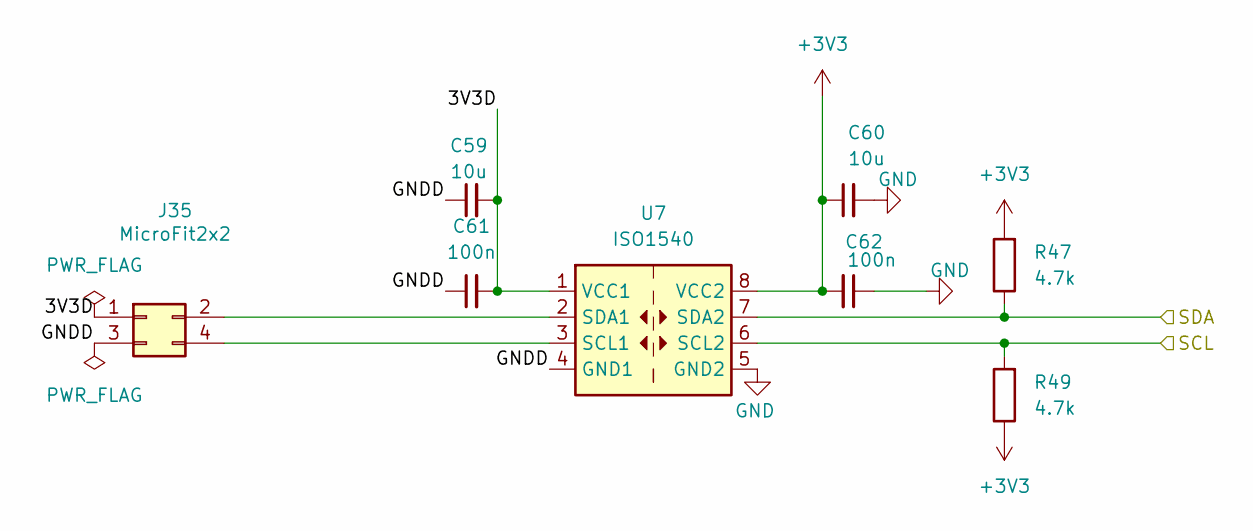
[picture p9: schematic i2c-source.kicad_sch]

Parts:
C59, C60: 10u; C_0805_2012Metric_Pad1.18x1.45mm_HandSolder; MPN CL21A106KBYQNNE
C61, C62: 100n; C_0805_2012Metric_Pad1.18x1.45mm_HandSolder; MPN CL21B104KBCNNND
J35: MicroFit2x2; J_Wurth_WR-MPC3_66200421122; MPN 66200421122
R47, R49: 4.7k; R_0805_2012Metric_Pad1.20x1.40mm_HandSolder; MPN CRCW08054K70FKEA
U7: ISO1540; SOIC-8_3.9x4.9mm_P1.27mm; MPN ISO1540DR

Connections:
+3V3: C60.1, C62.2, R47.2, R49.1, U7.8 (VCC2); also elsewhere on the board
/I2C Sporadic/3V3D: C59.2, C61.2, J35.1, U7.1 (VCC1)
/I2C Sporadic/GNDD: C59.1, C61.1, J35.3, U7.4 (GND1)
GND: C60.2, C62.1, U7.5 (GND2); also elsewhere on the board
unnamed: J35.2, U7.2 (SDA1)
unnamed: J35.4, U7.3 (SCL1)
SCL_SPORADIC: R49.2, U7.6 (SCL2); also elsewhere on the board
SDA_SPORADIC: R47.1, U7.7 (SDA2); also elsewhere on the board

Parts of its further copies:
C63, C64: 10u; C_0805_2012Metric_Pad1.18x1.45mm_HandSolder; MPN CL21A106KBYQNNE
C65, C66: 100n; C_0805_2012Metric_Pad1.18x1.45mm_HandSolder; MPN CL21B104KBCNNND
J36: MicroFit2x2; J_Wurth_WR-MPC3_66200421122; MPN 66200421122
R54, R56: 4.7k; R_0805_2012Metric_Pad1.20x1.40mm_HandSolder; MPN CRCW08054K70FKEA
U8: ISO1540; SOIC-8_3.9x4.9mm_P1.27mm; MPN ISO1540DR

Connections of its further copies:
+3V3: C64.1, C66.2, R54.2, R56.1, U8.8 (VCC2); also elsewhere on the board
/I2C Realtime/3V3D: C63.2, C65.2, J36.1, U8.1 (VCC1)
/I2C Realtime/GNDD: C63.1, C65.1, J36.3, U8.4 (GND1)
GND: C64.2, C66.1, U8.5 (GND2); also elsewhere on the board
unnamed: J36.2, U8.2 (SDA1)
unnamed: J36.4, U8.3 (SCL1)
SCL_REALTIME: R56.2, U8.6 (SCL2); also elsewhere on the board
SDA_REALTIME: R54.1, U8.7 (SDA2); also elsewhere on the board

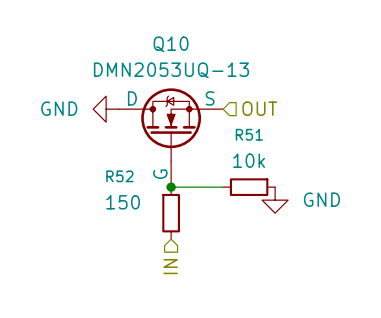
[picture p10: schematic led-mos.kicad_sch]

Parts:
Q10: DMN2053UQ-13; SOT-23_Handsoldering-DMN2053UQ; MPN DMN2053UQ-13
R51: 10k; R_0805_2012Metric_Pad1.20x1.40mm_HandSolder; MPN CRCW080510K0FKEA
R52: 150; R_0805_2012Metric_Pad1.20x1.40mm_HandSolder; MPN CRCW0805150RFKEA

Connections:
/LED_G: R52.2; also elsewhere on the board
/Led Green/OUT: Q10.3 (S); also elsewhere on the board
GND: Q10.1 (D), R51.1; also elsewhere on the board
unnamed: Q10.2 (G), R51.2, R52.1

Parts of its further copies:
Q11, Q12: DMN2053UQ-13; SOT-23_Handsoldering-DMN2053UQ; MPN DMN2053UQ-13
R57, R59: 10k; R_0805_2012Metric_Pad1.20x1.40mm_HandSolder; MPN CRCW080510K0FKEA
R58, R60: 150; R_0805_2012Metric_Pad1.20x1.40mm_HandSolder; MPN CRCW0805150RFKEA

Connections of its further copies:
/LED_B: R58.2; also elsewhere on the board
/LED_R: R60.2; also elsewhere on the board
/Led Blue/OUT: Q11.3 (S); also elsewhere on the board
/Led Red/OUT: Q12.3 (S); also elsewhere on the board
GND: Q11.1 (D), Q12.1 (D), R57.1, R59.1; also elsewhere on the board
unnamed: Q11.2 (G), R57.2, R58.1
unnamed: Q12.2 (G), R59.2, R60.1

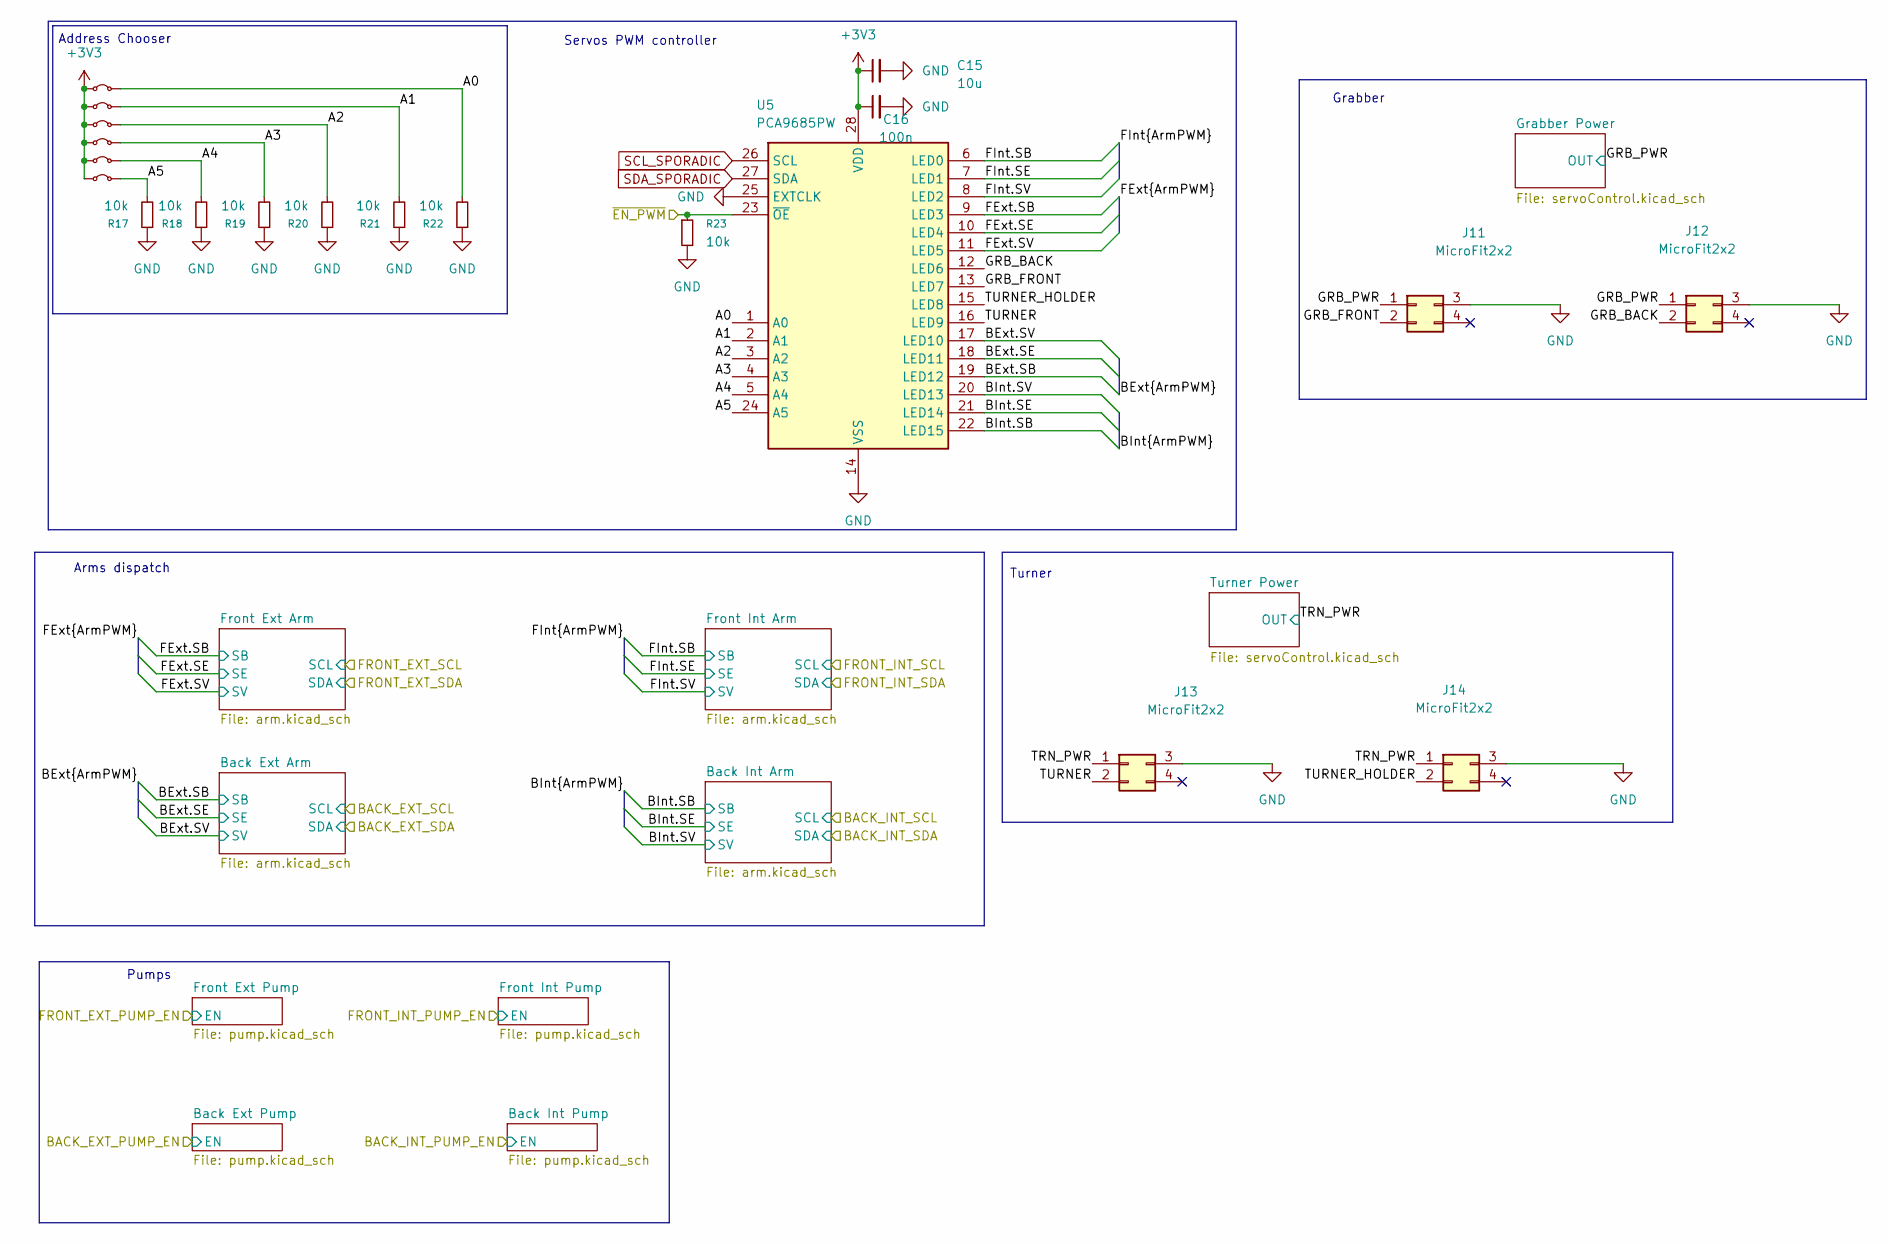
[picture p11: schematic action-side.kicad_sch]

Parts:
C15: 10u; C_0805_2012Metric_Pad1.18x1.45mm_HandSolder; MPN CL21A106KBYQNNE
C16: 100n; C_0805_2012Metric_Pad1.18x1.45mm_HandSolder; MPN CL21B104KBCNNND
J11, J12, J13, J14: MicroFit2x2; J_Wurth_WR-MPC3_66200421122; MPN 66200421122
NT13, NT14, NT15, NT16, NT17, NT18: Jumper_2_Bridged; TestPoint_2Pads_Pitch2.54mm_Drill0.8mm; MPN M7582-46
R17, R18, R19, R20, R21, R22, R23: 10k; R_0805_2012Metric_Pad1.20x1.40mm_HandSolder; MPN CRCW080510K0FKEA
U5: PCA9685PW; TSSOP-28_4.4x9.7mm_P0.65mm; MPN PCA9685PW,118

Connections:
+3V3: C15.1, C16.1, NT13.1 (A), NT14.1 (A), NT15.1 (A), NT16.1 (A), NT17.1 (A), NT18.1 (A), U5.28 (VDD); also elsewhere on the board
+6V: J11.1, J12.1, J13.1, J14.1; also elsewhere on the board
/Left Side/A0: NT13.2 (B), R22.2, U5.1 (A0)
/Left Side/A1: NT14.2 (B), R21.2, U5.2 (A1)
/Left Side/A2: NT15.2 (B), R20.2, U5.3 (A2)
/Left Side/A3: NT16.2 (B), R19.2, U5.4 (A3)
/Left Side/A4: NT17.2 (B), R18.2, U5.5 (A4)
/Left Side/A5: NT18.2 (B), R17.2, U5.24 (A5)
/Left Side/BExt.SB: U5.19 (LED12); also elsewhere on the board
/Left Side/BExt.SE: U5.18 (LED11); also elsewhere on the board
/Left Side/BExt.SV: U5.17 (LED10); also elsewhere on the board
/Left Side/BInt.SB: U5.22 (LED15); also elsewhere on the board
/Left Side/BInt.SE: U5.21 (LED14); also elsewhere on the board
/Left Side/BInt.SV: U5.20 (LED13); also elsewhere on the board
/Left Side/FExt.SB: U5.9 (LED3); also elsewhere on the board
/Left Side/FExt.SE: U5.10 (LED4); also elsewhere on the board
/Left Side/FExt.SV: U5.11 (LED5); also elsewhere on the board
/Left Side/FInt.SB: U5.6 (LED0); also elsewhere on the board
/Left Side/FInt.SE: U5.7 (LED1); also elsewhere on the board
/Left Side/FInt.SV: U5.8 (LED2); also elsewhere on the board
/Left Side/GRB_BACK: J12.2, U5.12 (LED6)
/Left Side/GRB_FRONT: J11.2, U5.13 (LED7)
/Left Side/TURNER: J13.2, U5.16 (LED9)
/Left Side/TURNER_HOLDER: J14.2, U5.15 (LED8)
/~EN_L_PWM: R23.1, U5.23 (~OE); also elsewhere on the board
GND: C15.2, C16.2, J11.3, J12.3, J13.3, J14.3, R17.1, R18.1, R19.1, R20.1, R21.1, R22.1, R23.2, U5.14 (VSS), U5.25 (EXTCLK); also elsewhere on the board
SCL_SPORADIC: U5.26 (SCL); also elsewhere on the board
SDA_SPORADIC: U5.27 (SDA); also elsewhere on the board

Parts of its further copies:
C21: 10u; C_0805_2012Metric_Pad1.18x1.45mm_HandSolder; MPN CL21A106KBYQNNE
C22: 100n; C_0805_2012Metric_Pad1.18x1.45mm_HandSolder; MPN CL21B104KBCNNND
J17, J18, J19, J20: MicroFit2x2; J_Wurth_WR-MPC3_66200421122; MPN 66200421122
NT19, NT20, NT21, NT22, NT23, NT24: Jumper_2_Bridged; TestPoint_2Pads_Pitch2.54mm_Drill0.8mm; MPN M7582-46
R26, R27, R28, R29, R30, R31, R32: 10k; R_0805_2012Metric_Pad1.20x1.40mm_HandSolder; MPN CRCW080510K0FKEA
U6: PCA9685PW; TSSOP-28_4.4x9.7mm_P0.65mm; MPN PCA9685PW,118

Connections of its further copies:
+3V3: C21.1, C22.1, NT19.1 (A), NT20.1 (A), NT21.1 (A), NT22.1 (A), NT23.1 (A), NT24.1 (A), U6.28 (VDD); also elsewhere on the board
+6V: J17.1, J18.1, J19.1, J20.1; also elsewhere on the board
/Right Side/A0: NT19.2 (B), R31.2, U6.1 (A0)
/Right Side/A1: NT20.2 (B), R30.2, U6.2 (A1)
/Right Side/A2: NT21.2 (B), R29.2, U6.3 (A2)
/Right Side/A3: NT22.2 (B), R28.2, U6.4 (A3)
/Right Side/A4: NT23.2 (B), R27.2, U6.5 (A4)
/Right Side/A5: NT24.2 (B), R26.2, U6.24 (A5)
/Right Side/BExt.SB: U6.19 (LED12); also elsewhere on the board
/Right Side/BExt.SE: U6.18 (LED11); also elsewhere on the board
/Right Side/BExt.SV: U6.17 (LED10); also elsewhere on the board
/Right Side/BInt.SB: U6.22 (LED15); also elsewhere on the board
/Right Side/BInt.SE: U6.21 (LED14); also elsewhere on the board
/Right Side/BInt.SV: U6.20 (LED13); also elsewhere on the board
/Right Side/FExt.SB: U6.9 (LED3); also elsewhere on the board
/Right Side/FExt.SE: U6.10 (LED4); also elsewhere on the board
/Right Side/FExt.SV: U6.11 (LED5); also elsewhere on the board
/Right Side/FInt.SB: U6.6 (LED0); also elsewhere on the board
/Right Side/FInt.SE: U6.7 (LED1); also elsewhere on the board
/Right Side/FInt.SV: U6.8 (LED2); also elsewhere on the board
/Right Side/GRB_BACK: J18.2, U6.12 (LED6)
/Right Side/GRB_FRONT: J17.2, U6.13 (LED7)
/Right Side/TURNER: J19.2, U6.16 (LED9)
/Right Side/TURNER_HOLDER: J20.2, U6.15 (LED8)
/~EN_R_PWM: R32.1, U6.23 (~OE); also elsewhere on the board
GND: C21.2, C22.2, J17.3, J18.3, J19.3, J20.3, R26.1, R27.1, R28.1, R29.1, R30.1, R31.1, R32.2, U6.14 (VSS), U6.25 (EXTCLK); also elsewhere on the board
SCL_SPORADIC: U6.26 (SCL); also elsewhere on the board
SDA_SPORADIC: U6.27 (SDA); also elsewhere on the board

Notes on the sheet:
Address Chooser
Grabber
Arms dispatch
Pumps
Turner
Servos PWM controller

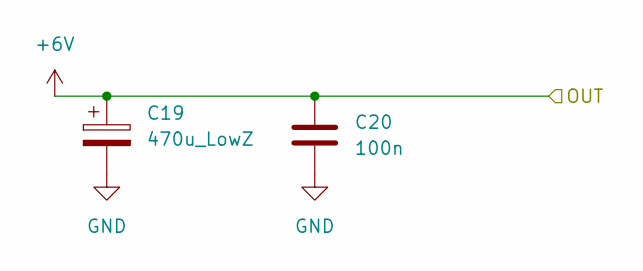
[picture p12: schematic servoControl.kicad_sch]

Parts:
C19: 470u_LowZ; CP_Radial_D10.0mm_P5.00mm; MPN EEU-FR1E471
C20: 100n; C_0805_2012Metric_Pad1.18x1.45mm_HandSolder; MPN CL21B104KBCNNND

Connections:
+6V: C19.1, C20.1; also elsewhere on the board
GND: C19.2, C20.2; also elsewhere on the board

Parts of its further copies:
C23, C25, C29, C41, C43, C45, C47, C49, C53, C55, C57, C67: 470u_LowZ; CP_Radial_D10.0mm_P5.00mm; MPN EEU-FR1E471
C24, C26, C30, C42, C44, C46, C48, C50, C54, C56, C58, C68: 100n; C_0805_2012Metric_Pad1.18x1.45mm_HandSolder; MPN CL21B104KBCNNND

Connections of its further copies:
+6V: C23.1, C24.1, C25.1, C26.1, C29.1, C30.1, C41.1, C42.1, C43.1, C44.1, C45.1, C46.1, C47.1, C48.1, C49.1, C50.1, C53.1, C54.1, C55.1, C56.1, C57.1, C58.1, C67.1, C68.1; also elsewhere on the board
GND: C23.2, C24.2, C25.2, C26.2, C29.2, C30.2, C41.2, C42.2, C43.2, C44.2, C45.2, C46.2, C47.2, C48.2, C49.2, C50.2, C53.2, C54.2, C55.2, C56.2, C57.2, C58.2, C67.2, C68.2; also elsewhere on the board

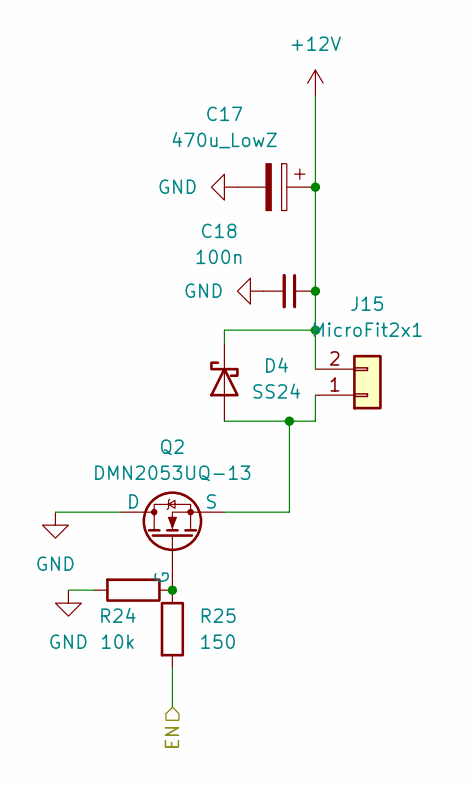
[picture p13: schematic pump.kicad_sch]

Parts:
C17: 470u_LowZ; CP_Radial_D10.0mm_P5.00mm; MPN EEU-FR1E471
C18: 100n; C_0805_2012Metric_Pad1.18x1.45mm_HandSolder; MPN CL21B104KBCNNND
D4: SS24; D_SMA_Handsoldering; MPN SS24S-E3/5AT
J15: MicroFit2x1; J_Wurth_WR-MPC3_66200211122; MPN 66200211122
Q2: DMN2053UQ-13; SOT-23_Handsoldering-DMN2053UQ; MPN DMN2053UQ-13
R24: 10k; R_0805_2012Metric_Pad1.20x1.40mm_HandSolder; MPN CRCW080510K0FKEA
R25: 150; R_0805_2012Metric_Pad1.20x1.40mm_HandSolder; MPN CRCW0805150RFKEA

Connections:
+12V: C17.1, C18.1, D4.1 (K), J15.2; also elsewhere on the board
/BACK_INT_L_P: R25.2; also elsewhere on the board
GND: C17.2, C18.2, Q2.1 (D), R24.2; also elsewhere on the board
unnamed: D4.2 (A), J15.1, Q2.3 (S)
unnamed: Q2.2 (G), R24.1, R25.1

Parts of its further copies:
C27, C31, C33, C35, C37, C39, C51: 470u_LowZ; CP_Radial_D10.0mm_P5.00mm; MPN EEU-FR1E471
C28, C32, C34, C36, C38, C40, C52: 100n; C_0805_2012Metric_Pad1.18x1.45mm_HandSolder; MPN CL21B104KBCNNND
D5, D6, D7, D8, D9, D10, D11: SS24; D_SMA_Handsoldering; MPN SS24S-E3/5AT
J23, J24, J25, J26, J27, J28, J33: MicroFit2x1; J_Wurth_WR-MPC3_66200211122; MPN 66200211122
Q3, Q4, Q5, Q6, Q7, Q8, Q9: DMN2053UQ-13; SOT-23_Handsoldering-DMN2053UQ; MPN DMN2053UQ-13
R33, R35, R37, R39, R41, R43, R45: 10k; R_0805_2012Metric_Pad1.20x1.40mm_HandSolder; MPN CRCW080510K0FKEA
R34, R36, R38, R40, R42, R44, R46: 150; R_0805_2012Metric_Pad1.20x1.40mm_HandSolder; MPN CRCW0805150RFKEA

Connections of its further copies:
+12V: C27.1, C28.1, C31.1, C32.1, C33.1, C34.1, C35.1, C36.1, C37.1, C38.1, C39.1, C40.1, C51.1, C52.1, D5.1 (K), D6.1 (K), D7.1 (K), D8.1 (K), D9.1 (K), D10.1 (K), D11.1 (K), J23.2, J24.2, J25.2, J26.2, J27.2, J28.2, J33.2; also elsewhere on the board
/BACK_EXT_L_P: R36.2; also elsewhere on the board
/BACK_EXT_R_P: R40.2; also elsewhere on the board
/BACK_INT_R_P: R44.2; also elsewhere on the board
/FRONT_EXT_L_P: R46.2; also elsewhere on the board
/FRONT_EXT_R_P: R42.2; also elsewhere on the board
/FRONT_INT_L_P: R34.2; also elsewhere on the board
/FRONT_INT_R_P: R38.2; also elsewhere on the board
GND: C27.2, C28.2, C31.2, C32.2, C33.2, C34.2, C35.2, C36.2, C37.2, C38.2, C39.2, C40.2, C51.2, C52.2, Q3.1 (D), Q4.1 (D), Q5.1 (D), Q6.1 (D), Q7.1 (D), Q8.1 (D), Q9.1 (D), R33.2, R35.2, R37.2, R39.2, R41.2, R43.2, R45.2; also elsewhere on the board
unnamed: D5.2 (A), J23.1, Q3.3 (S)
unnamed: D6.2 (A), J24.1, Q4.3 (S)
unnamed: D7.2 (A), J25.1, Q5.3 (S)
unnamed: D8.2 (A), J26.1, Q6.3 (S)
unnamed: D9.2 (A), J27.1, Q7.3 (S)
unnamed: D10.2 (A), J28.1, Q8.3 (S)
unnamed: D11.2 (A), J33.1, Q9.3 (S)
unnamed: Q3.2 (G), R33.1, R34.1
unnamed: Q4.2 (G), R35.1, R36.1
unnamed: Q5.2 (G), R37.1, R38.1
unnamed: Q6.2 (G), R39.1, R40.1
unnamed: Q7.2 (G), R41.1, R42.1
unnamed: Q8.2 (G), R43.1, R44.1
unnamed: Q9.2 (G), R45.1, R46.1

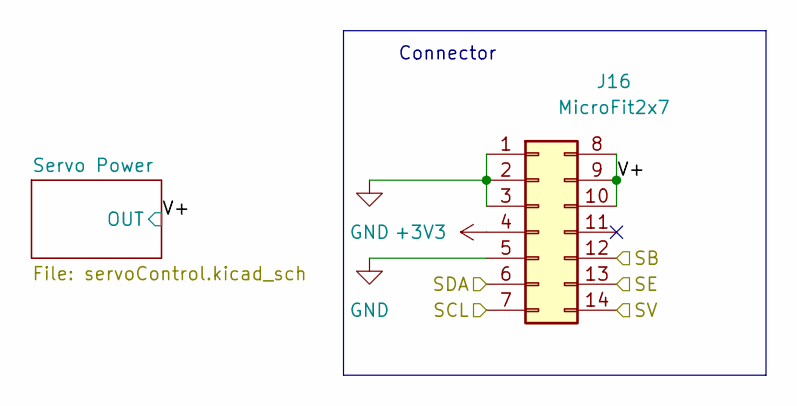
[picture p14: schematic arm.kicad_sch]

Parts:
J16: MicroFit2x7; J_Wurth_WR-MPC3_66201421122; MPN 43045-1412

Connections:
+3V3: J16.4; also elsewhere on the board
+6V: J16.8, J16.9, J16.10; also elsewhere on the board
/BACK_EXT_L_SCL: J16.7; also elsewhere on the board
/BACK_EXT_L_SDA: J16.6; also elsewhere on the board
/Left Side/BExt.SB: J16.12; also elsewhere on the board
/Left Side/BExt.SE: J16.13; also elsewhere on the board
/Left Side/BExt.SV: J16.14; also elsewhere on the board
GND: J16.1, J16.2, J16.3, J16.5; also elsewhere on the board

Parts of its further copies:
J21, J22, J29, J30, J31, J32, J34: MicroFit2x7; J_Wurth_WR-MPC3_66201421122; MPN 43045-1412

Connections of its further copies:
+3V3: J21.4, J22.4, J29.4, J30.4, J31.4, J32.4, J34.4; also elsewhere on the board
+6V: J21.8, J21.9, J21.10, J22.8, J22.9, J22.10, J29.8, J29.9, J29.10, J30.8, J30.9, J30.10, J31.8, J31.9, J31.10, J32.8, J32.9, J32.10, J34.8, J34.9, J34.10; also elsewhere on the board
/BACK_EXT_R_SCL: J22.7; also elsewhere on the board
/BACK_EXT_R_SDA: J22.6; also elsewhere on the board
/BACK_INT_L_SCL: J30.7; also elsewhere on the board
/BACK_INT_L_SDA: J30.6; also elsewhere on the board
/BACK_INT_R_SCL: J34.7; also elsewhere on the board
/BACK_INT_R_SDA: J34.6; also elsewhere on the board
/FRONT_EXT_L_SCL: J32.7; also elsewhere on the board
/FRONT_EXT_L_SDA: J32.6; also elsewhere on the board
/FRONT_EXT_R_SCL: J29.7; also elsewhere on the board
/FRONT_EXT_R_SDA: J29.6; also elsewhere on the board
/FRONT_INT_L_SCL: J21.7; also elsewhere on the board
/FRONT_INT_L_SDA: J21.6; also elsewhere on the board
/FRONT_INT_R_SCL: J31.7; also elsewhere on the board
/FRONT_INT_R_SDA: J31.6; also elsewhere on the board
/Left Side/BInt.SB: J30.12; also elsewhere on the board
/Left Side/BInt.SE: J30.13; also elsewhere on the board
/Left Side/BInt.SV: J30.14; also elsewhere on the board
/Left Side/FExt.SB: J32.12; also elsewhere on the board
/Left Side/FExt.SE: J32.13; also elsewhere on the board
/Left Side/FExt.SV: J32.14; also elsewhere on the board
/Left Side/FInt.SB: J21.12; also elsewhere on the board
/Left Side/FInt.SE: J21.13; also elsewhere on the board
/Left Side/FInt.SV: J21.14; also elsewhere on the board
/Right Side/BExt.SB: J22.12; also elsewhere on the board
/Right Side/BExt.SE: J22.13; also elsewhere on the board
/Right Side/BExt.SV: J22.14; also elsewhere on the board
/Right Side/BInt.SB: J34.12; also elsewhere on the board
/Right Side/BInt.SE: J34.13; also elsewhere on the board
/Right Side/BInt.SV: J34.14; also elsewhere on the board
/Right Side/FExt.SB: J29.12; also elsewhere on the board
/Right Side/FExt.SE: J29.13; also elsewhere on the board
/Right Side/FExt.SV: J29.14; also elsewhere on the board
/Right Side/FInt.SB: J31.12; also elsewhere on the board
/Right Side/FInt.SE: J31.13; also elsewhere on the board
/Right Side/FInt.SV: J31.14; also elsewhere on the board
GND: J21.1, J21.2, J21.3, J21.5, J22.1, J22.2, J22.3, J22.5, J29.1, J29.2, J29.3, J29.5, J30.1, J30.2, J30.3, J30.5, J31.1, J31.2, J31.3, J31.5, J32.1, J32.2, J32.3, J32.5, J34.1, J34.2, J34.3, J34.5; also elsewhere on the board

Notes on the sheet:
Connector

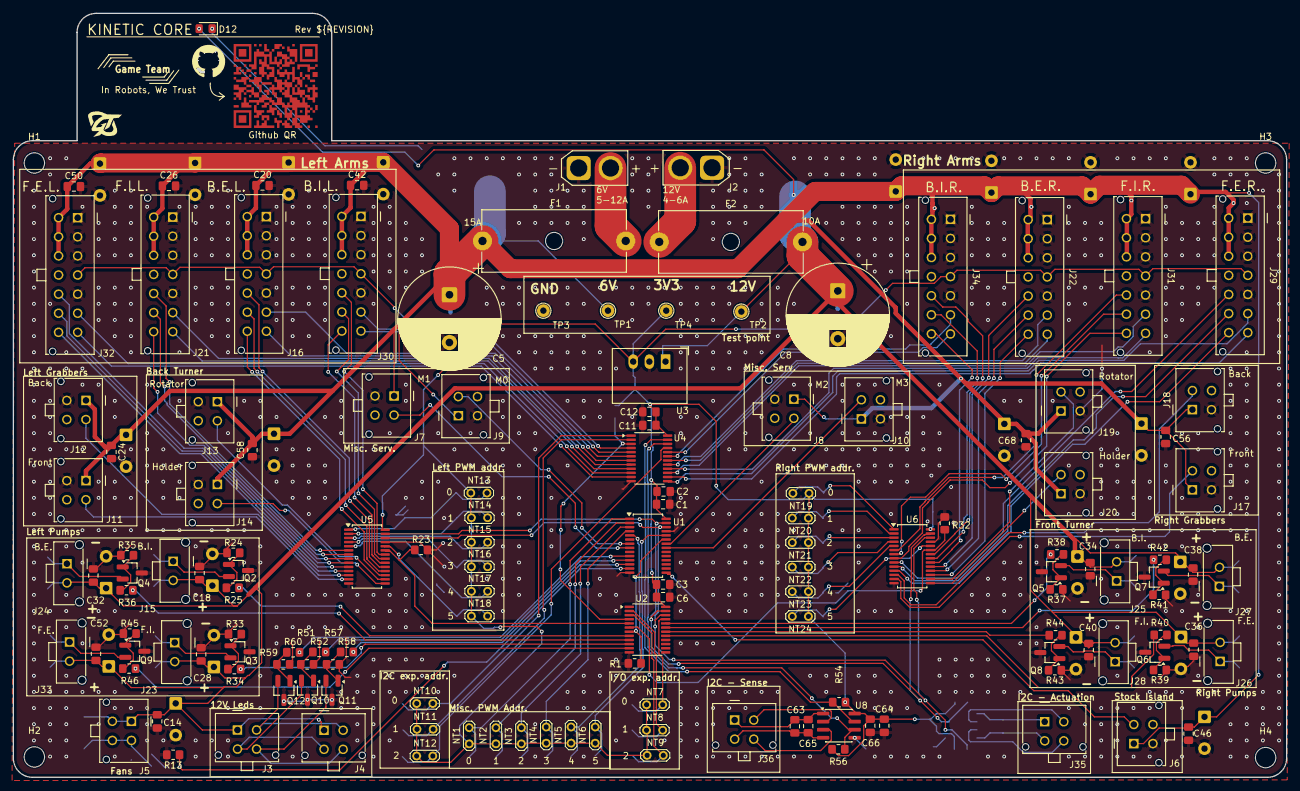
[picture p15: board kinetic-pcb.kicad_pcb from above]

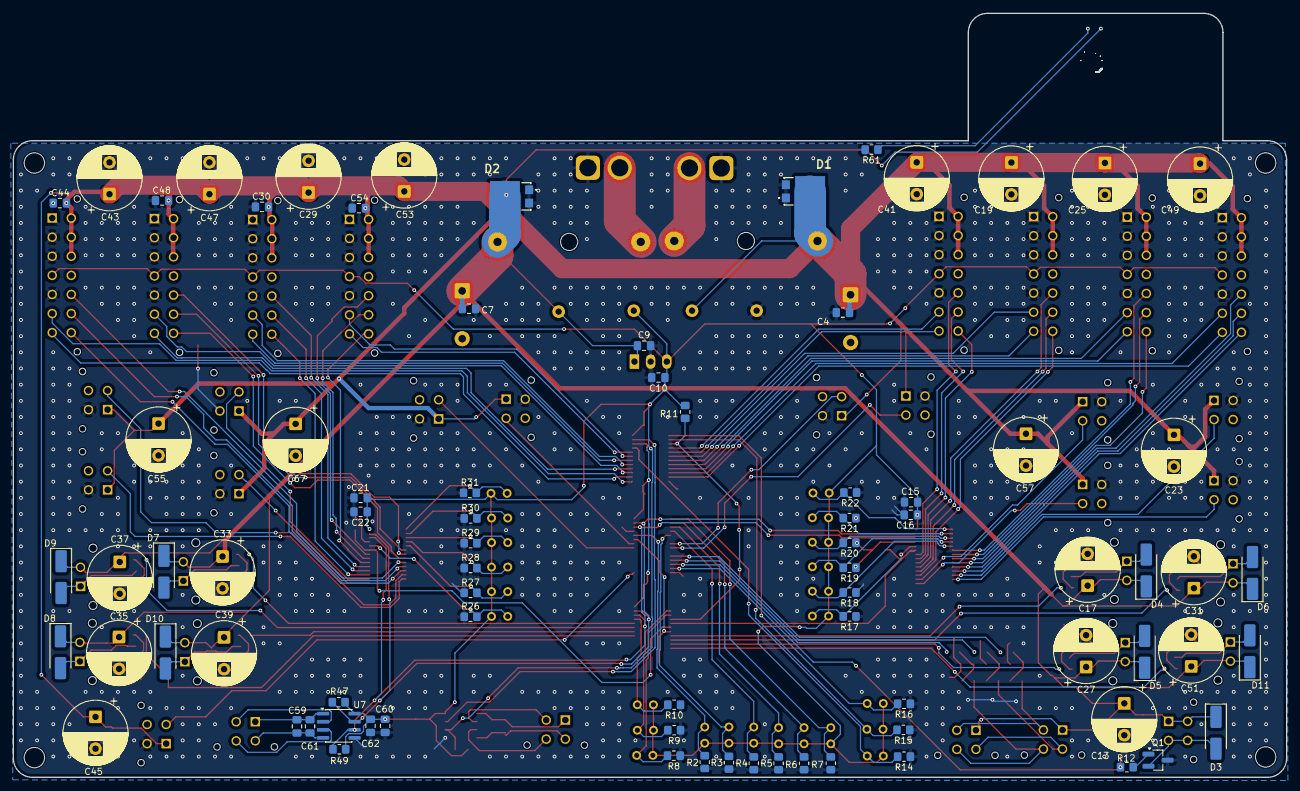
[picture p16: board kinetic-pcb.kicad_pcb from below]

Board: 2 copper layers, 200.0 x 120.0 mm, 228 parts (80 on the bottom side), 136 nets.

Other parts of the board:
QR*****: Github QR

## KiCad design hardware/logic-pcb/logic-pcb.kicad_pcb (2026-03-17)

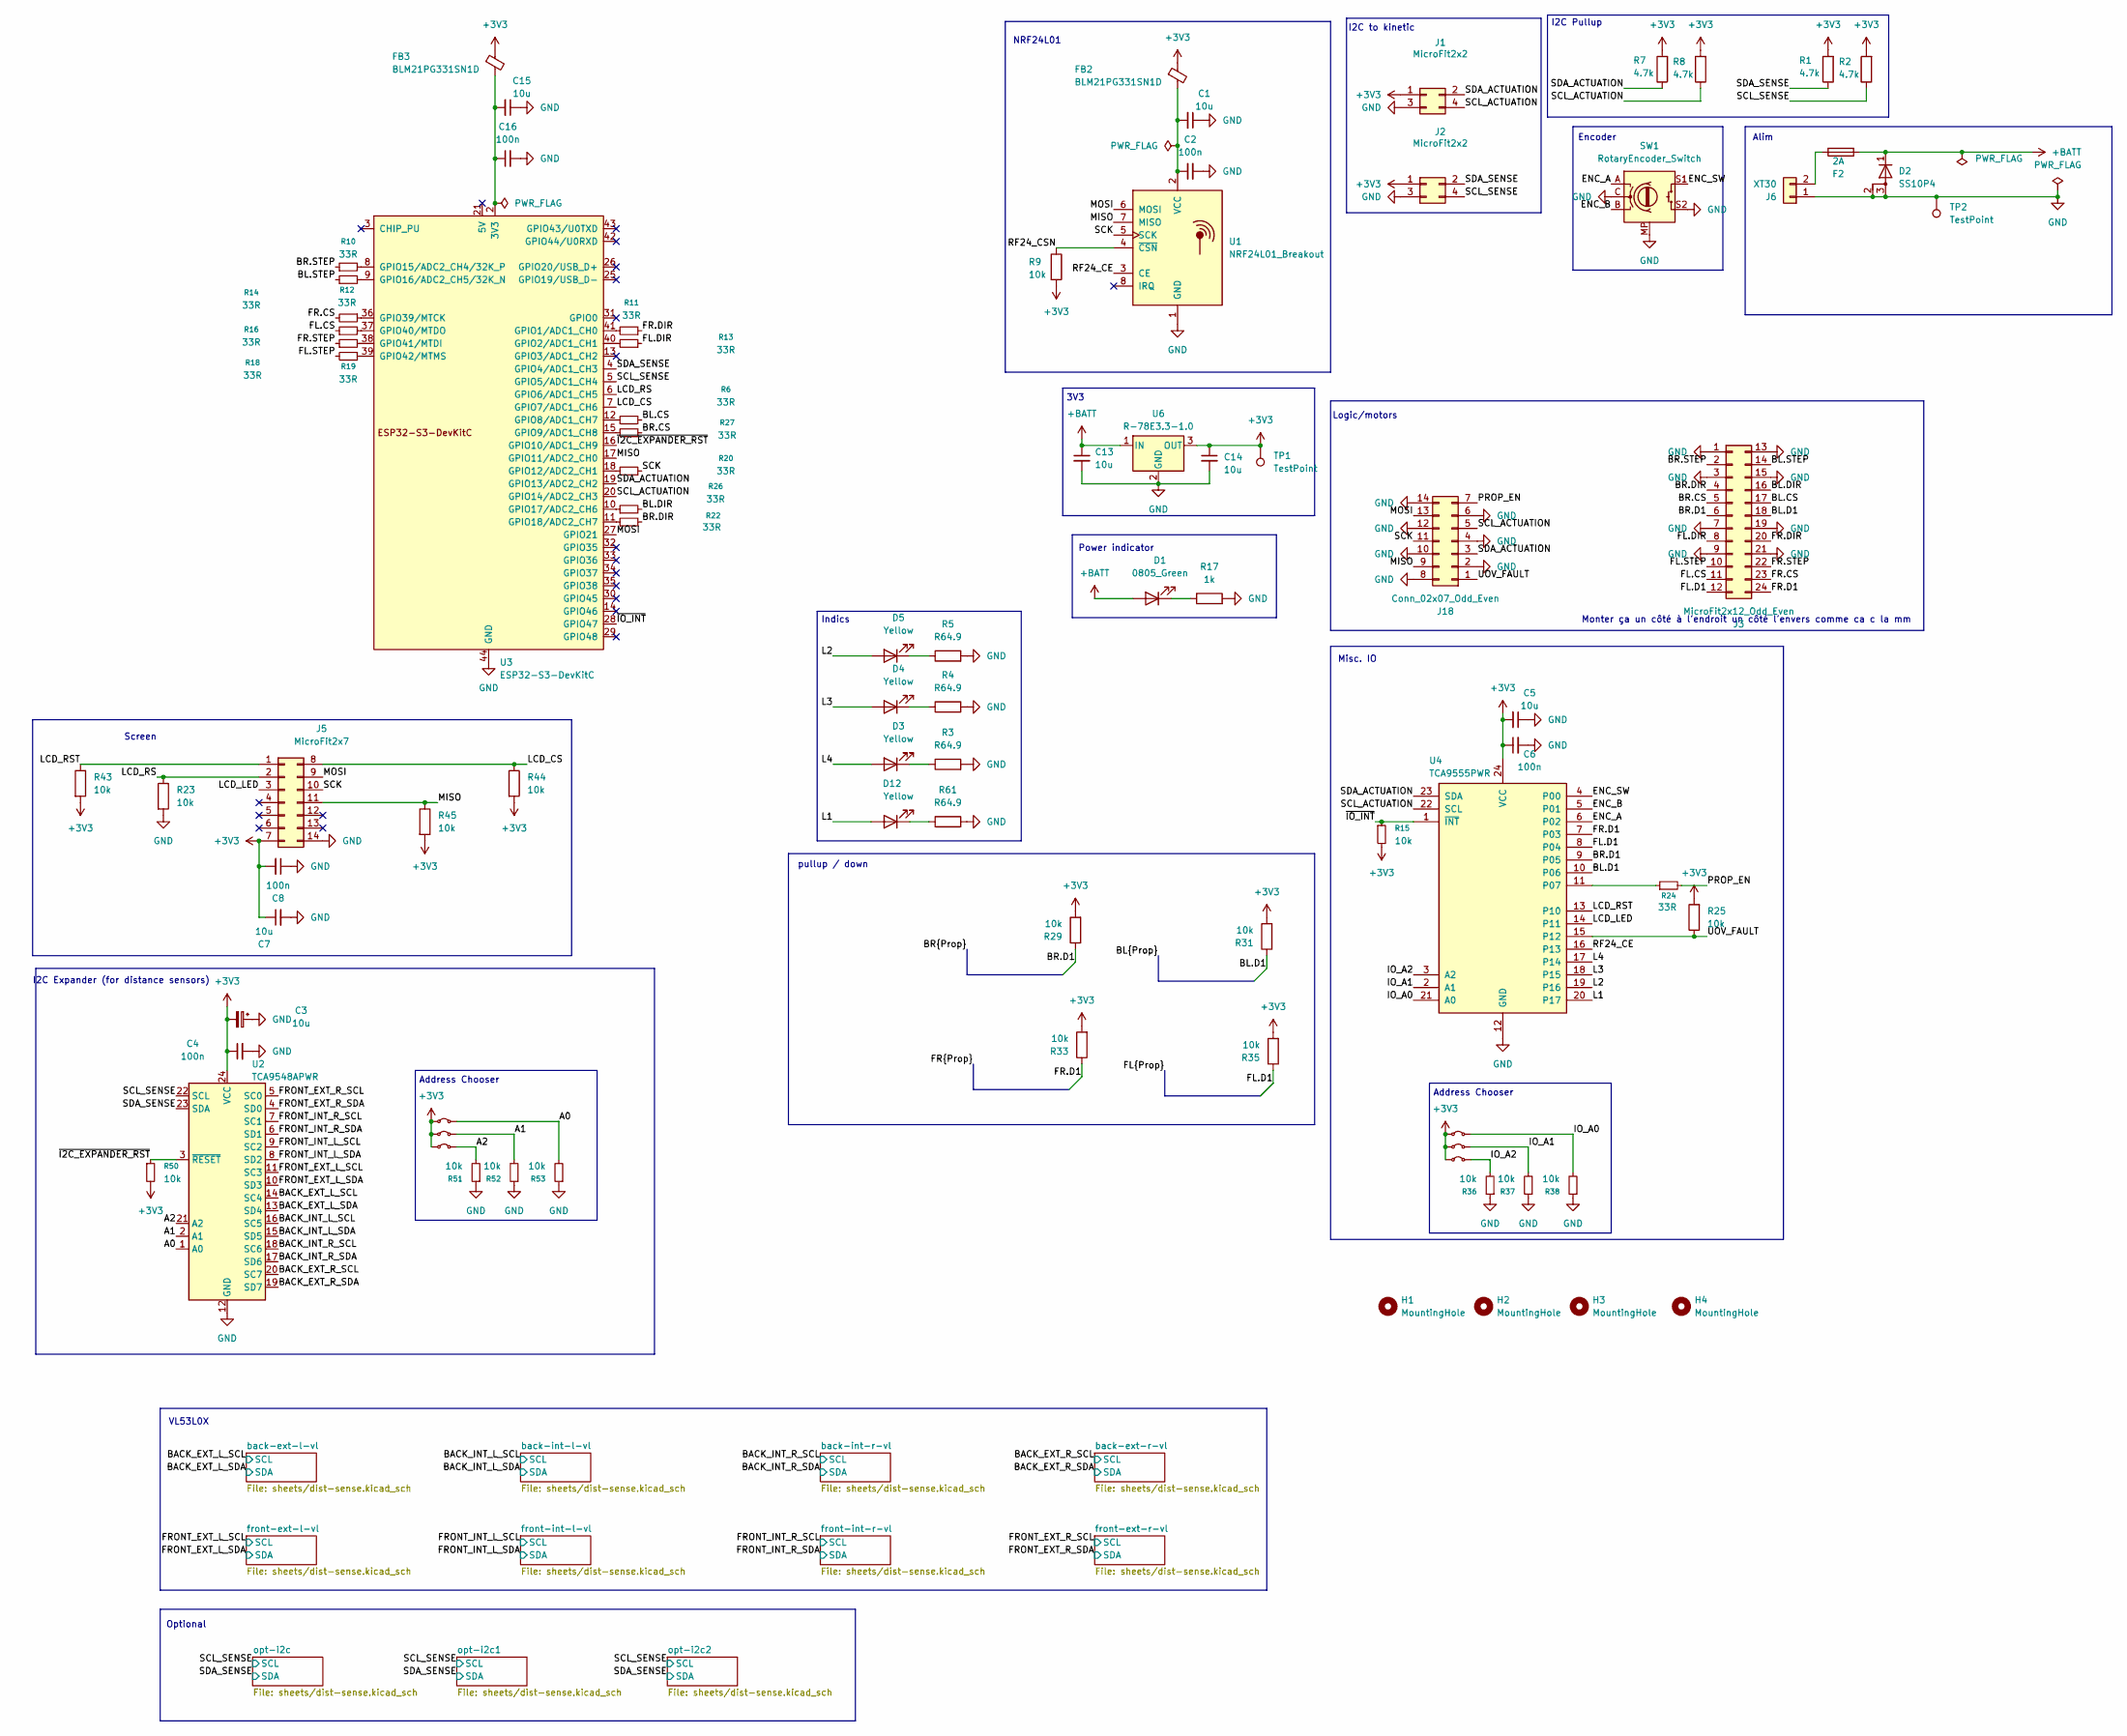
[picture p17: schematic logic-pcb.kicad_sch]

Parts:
C1, C3, C5, C7, C13, C14, C15: 10u; C_0805_2012Metric_Pad1.18x1.45mm_HandSolder; MPN CL21A106KBYQNNE
C2, C4, C6, C8, C16: 100n; C_0805_2012Metric_Pad1.18x1.45mm_HandSolder; MPN CL21B104KBCNNND
D1: 0805_Green; LED_0805_2012Metric_Pad1.15x1.40mm_HandSolder; MPN APA2106ZGCK
D2: SS10P4; SS10P4M387A; MPN SS10P4-M3/87A
D3, D4, D5, D12: Yellow; LED_0805_2012Metric_Pad1.15x1.40mm_HandSolder; MPN APA2106SYCK
F2: 2A; Fuseholder_Cylinder-5x20mm_Schurter_0031_8201_Horizontal_Op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
FB2, FB3: BLM21PG331SN1D; L_0805_2012Metric_Pad1.05x1.20mm_HandSolder; MPN BLM21PG331SN1D
H1, H2, H3, H4: MountingHole; MountingHole_3.2mm_M3
J1, J2: MicroFit2x2; J_Wurth_WR-MPC3_66200421122; MPN 66200421122
J3: MicroFit2x12_Odd_Even; J_Wurth_WR-MPC3_66202421122; MPN 43045-2412
J5: MicroFit2x7; J_Wurth_WR-MPC3_66201421122; MPN 43045-1412
J6: XT30; AMASS_XT30U-M_1x02_P5.0mm_Vertical
J18: Conn_02x07_Odd_Even; J_Wurth_WR-MPC3_66201421122; MPN 43045-1412
NT1, NT2, NT3, NT10, NT11, NT12: Jumper_2_Bridged; TestPoint_2Pads_Pitch2.54mm_Drill0.8mm; MPN M7582-46
R1, R2, R7, R8: 4.7k; R_0805_2012Metric_Pad1.20x1.40mm_HandSolder; MPN CRCW08054K70FKEA
R3, R4, R5, R61: R64.9; R_0805_2012Metric_Pad1.20x1.40mm_HandSolder; MPN CRCW08051K00FKEA
R6, R10, R11, R12, R13, R14, R16, R18, R19, R20, R22, R24, R26, R27: 33R; R_0805_2012Metric_Pad1.20x1.40mm_HandSolder; MPN CRCW080533R0FKEA
R9, R15, R23, R25, R29, R31, R33, R35, R36, R37, R38, R43, R44, R45, R50, R51, R52, R53: 10k; R_0805_2012Metric_Pad1.20x1.40mm_HandSolder; MPN CRCW080510K0FKEA
R17: 1k; R_0805_2012Metric_Pad1.20x1.40mm_HandSolder; MPN CRCW08051K00FKEA
SW1: RotaryEncoder_Switch; RotaryEncoder_Alps_EC11E-Switch_Vertical_H20mm; MPN EC11E15204A3
TP1, TP2: TestPoint; TestPoint_THTPad_D1.0mm_Drill0.5mm
U1: NRF24L01_Breakout; nRF24L01+_Breakout
U2: TCA9548APWR; TSSOP-24_4.4x7.8mm_P0.65mm; MPN TCA9548APWR
U3: ESP32-S3-DevKitC; MPN ESP32-S3-DevKitC-1-N8R8
U4: TCA9555PWR; TSSOP-24_4.4x7.8mm_P0.65mm; MPN TCA9555PWR
U6: R-78E3.3-1.0; Converter_DCDC_RECOM_R-78E-0.5_THT; MPN R-78E3.3-1.0

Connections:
+3V3: C3.2, C4.1, C5.2, C6.1, C7.1, C8.2, C14.1, FB2.1, FB3.1, J1.1, J2.1, J5.7, NT1.1 (A), NT2.1 (A), NT3.1 (A), NT10.1 (A), NT11.1 (A), NT12.1 (A), R1.2, R2.2, R7.2, R8.2, R9.2, R15.2, R25.2, R29.2, R31.2, R33.2, R35.2, R43.2, R44.2, R45.2, R50.2, TP1.1, U2.24 (VCC), U4.24 (VCC), U6.3 (OUT); also elsewhere on the board
+BATT: C13.1, D1.2 (A), D2.1 (K), F2.2, U6.1 (IN)
/A0: NT10.2 (B), R53.2, U2.1 (A0)
/A1: NT11.2 (B), R52.2, U2.2 (A1)
/A2: NT12.2 (B), R51.2, U2.21 (A2)
/BACK_EXT_L_SCL: U2.14 (SC4); also elsewhere on the board
/BACK_EXT_L_SDA: U2.13 (SD4); also elsewhere on the board
/BACK_EXT_R_SCL: U2.20 (SC7); also elsewhere on the board
/BACK_EXT_R_SDA: U2.19 (SD7); also elsewhere on the board
/BACK_INT_L_SCL: U2.16 (SC5); also elsewhere on the board
/BACK_INT_L_SDA: U2.15 (SD5); also elsewhere on the board
/BACK_INT_R_SCL: U2.18 (SC6); also elsewhere on the board
/BACK_INT_R_SDA: U2.17 (SD6); also elsewhere on the board
/BL.CS: J3.17, R6.2
/BL.D1: J3.18, R31.1, U4.10 (P06)
/BL.DIR: J3.16, R26.2
/BL.STEP: J3.14, R12.1
/BR.CS: J3.5, R27.2
/BR.D1: J3.6, R29.1, U4.9 (P05)
/BR.DIR: J3.4, R22.2
/BR.STEP: J3.2, R10.1
/ENC_A: SW1.A, U4.6 (P02)
/ENC_B: SW1.B, U4.5 (P01)
/ENC_SW: SW1.S1, U4.4 (P00)
/FL.CS: J3.11, R16.1
/FL.D1: J3.12, R35.1, U4.8 (P04)
/FL.DIR: J3.8, R13.1
/FL.STEP: J3.10, R19.2
/FR.CS: J3.23, R14.2
/FR.D1: J3.24, R33.1, U4.7 (P03)
/FR.DIR: J3.20, R11.1
/FR.STEP: J3.22, R18.1
/FRONT_EXT_L_SCL: U2.11 (SC3); also elsewhere on the board
/FRONT_EXT_L_SDA: U2.10 (SD3); also elsewhere on the board
/FRONT_EXT_R_SCL: U2.5 (SC0); also elsewhere on the board
/FRONT_EXT_R_SDA: U2.4 (SD0); also elsewhere on the board
/FRONT_INT_L_SCL: U2.9 (SC2); also elsewhere on the board
/FRONT_INT_L_SDA: U2.8 (SD2); also elsewhere on the board
/FRONT_INT_R_SCL: U2.7 (SC1); also elsewhere on the board
/FRONT_INT_R_SDA: U2.6 (SD1); also elsewhere on the board
/IO_A0: NT1.2 (B), R38.2, U4.21 (A0)
/IO_A1: NT2.2 (B), R37.2, U4.2 (A1)
/IO_A2: NT3.2 (B), R36.2, U4.3 (A2)
/L1: D12.2 (A), U4.20 (P17)
/L2: D5.2 (A), U4.19 (P16)
/L3: D4.2 (A), U4.18 (P15)
/L4: D3.2 (A), U4.17 (P14)
/LCD_CS: J5.8, R44.1, U3.7 (GPIO7/ADC1_CH6)
/LCD_LED: J5.3, U4.14 (P11)
/LCD_RS: J5.2, R23.1, U3.6 (GPIO6/ADC1_CH5)
/LCD_RST: J5.1, R43.1, U4.13 (P10)
/MISO: J5.11, J18.9, R45.1, U1.7 (MISO), U3.17 (GPIO11/ADC2_CH0)
/MOSI: J5.9, J18.13, U1.6 (MOSI), U3.27 (GPIO21)
/PROP_EN: J18.7, R24.2
/RF24_CE: U1.3 (CE), U4.16 (P13)
/RF24_CSN: R9.1, U1.4 (~CSN)
/SCK: J5.10, J18.11, R20.1, U1.5 (SCK)
/SCL_ACTUATION: J1.4, J18.5, R8.1, U3.20 (GPIO14/ADC2_CH3), U4.22 (SCL)
/SCL_SENSE: J2.4, R2.1, U2.22 (SCL), U3.5 (GPIO5/ADC1_CH4); also elsewhere on the board
/SDA_ACTUATION: J1.2, J18.3, R7.1, U3.19 (GPIO13/ADC2_CH2), U4.23 (SDA)
/SDA_SENSE: J2.2, R1.1, U2.23 (SDA), U3.4 (GPIO4/ADC1_CH3); also elsewhere on the board
/UOV_FAULT: J18.1, R25.1, U4.15 (P12)
/~I2C_EXPANDER_RST: R50.1, U2.3 (~RESET), U3.16 (GPIO10/ADC1_CH9)
/~IO_INT: R15.1, U3.28 (GPIO47), U4.1 (~INT)
GND: C1.1, C2.2, C3.1, C4.2, C5.1, C6.2, C7.2, C8.1, C13.2, C14.2, C15.1, C16.2, D2.2 (A), D2.3 (A), J1.3, J2.3, J3.1, J3.3, J3.7, J3.9, J3.13, J3.15, J3.19, J3.21, J5.14, J6.1, J18.2, J18.4, J18.6, J18.8, J18.10, J18.12, J18.14, R3.2, R4.2, R5.2, R17.2, R23.2, R36.1, R37.1, R38.1, R51.1, R52.1, R53.1, R61.2, SW1.C, SW1.MP, SW1.S2, TP2.1, U1.1 (GND), U2.12 (GND), U3.22 (GND), U3.23 (GND), U3.24 (GND), U3.44 (GND), U4.12 (GND), U6.2 (GND); also elsewhere on the board
unnamed: C15.2, C16.1, FB3.2, U3.1 (3V3), U3.2 (3V3)
unnamed: D1.1 (K), R17.1
unnamed: D3.1 (K), R3.1
unnamed: D4.1 (K), R4.1
unnamed: D5.1 (K), R5.1
unnamed: D12.1 (K), R61.1
unnamed: F2.1, J6.2
unnamed: C1.2, C2.1, FB2.2, U1.2 (VCC)
unnamed: R11.2, U3.41 (GPIO1/ADC1_CH0)
unnamed: R13.2, U3.40 (GPIO2/ADC1_CH1)
unnamed: R6.1, U3.12 (GPIO8/ADC1_CH7)
unnamed: R27.1, U3.15 (GPIO9/ADC1_CH8)
unnamed: R20.2, U3.18 (GPIO12/ADC2_CH1)
unnamed: R10.2, U3.8 (GPIO15/ADC2_CH4/32K_P)
unnamed: R12.2, U3.9 (GPIO16/ADC2_CH5/32K_N)
unnamed: R26.1, U3.10 (GPIO17/ADC2_CH6)
unnamed: R22.1, U3.11 (GPIO18/ADC2_CH7)
unnamed: R14.1, U3.36 (GPIO39/MTCK)
unnamed: R16.2, U3.37 (GPIO40/MTDO)
unnamed: R18.2, U3.38 (GPIO41/MTDI)
unnamed: R19.1, U3.39 (GPIO42/MTMS)
unnamed: R24.1, U4.11 (P07)

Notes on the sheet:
Address Chooser
VL53L0X
I2C Expander (for distance sensors)
Monter ça un côté à l'endroit un côté l'envers comme ca c la mm
Logic/motors
Indics
Alim
3V3
I2C Pullup
Misc. IO
pullup / down
Optional
Screen
NRF24L01
Encoder
Power indicator
I2C to kinetic

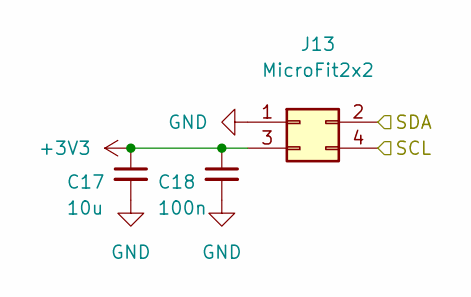
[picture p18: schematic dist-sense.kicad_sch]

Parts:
C17: 10u; C_0805_2012Metric_Pad1.18x1.45mm_HandSolder; MPN CL21A106KBYQNNE
C18: 100n; C_0805_2012Metric_Pad1.18x1.45mm_HandSolder; MPN CL21B104KBCNNND
J13: MicroFit2x2; J_Wurth_WR-MPC3_66200421122; MPN 66200421122

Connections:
+3V3: C17.1, C18.1, J13.3; also elsewhere on the board
/BACK_EXT_L_SCL: J13.4; also elsewhere on the board
/BACK_EXT_L_SDA: J13.2; also elsewhere on the board
GND: C17.2, C18.2, J13.1; also elsewhere on the board

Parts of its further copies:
C19, C21, C23, C25, C27, C29, C31, C33, C35, C37: 10u; C_0805_2012Metric_Pad1.18x1.45mm_HandSolder; MPN CL21A106KBYQNNE
C20, C22, C24, C26, C28, C30, C32, C34, C36, C38: 100n; C_0805_2012Metric_Pad1.18x1.45mm_HandSolder; MPN CL21B104KBCNNND
J7, J8, J9, J10, J11, J12, J14, J15, J16, J17: MicroFit2x2; J_Wurth_WR-MPC3_66200421122; MPN 66200421122

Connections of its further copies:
+3V3: C19.1, C20.1, C21.1, C22.1, C23.1, C24.1, C25.1, C26.1, C27.1, C28.1, C29.1, C30.1, C31.1, C32.1, C33.1, C34.1, C35.1, C36.1, C37.1, C38.1, J7.3, J8.3, J9.3, J10.3, J11.3, J12.3, J14.3, J15.3, J16.3, J17.3; also elsewhere on the board
/BACK_EXT_R_SCL: J12.4; also elsewhere on the board
/BACK_EXT_R_SDA: J12.2; also elsewhere on the board
/BACK_INT_L_SCL: J8.4; also elsewhere on the board
/BACK_INT_L_SDA: J8.2; also elsewhere on the board
/BACK_INT_R_SCL: J10.4; also elsewhere on the board
/BACK_INT_R_SDA: J10.2; also elsewhere on the board
/FRONT_EXT_L_SCL: J7.4; also elsewhere on the board
/FRONT_EXT_L_SDA: J7.2; also elsewhere on the board
/FRONT_EXT_R_SCL: J14.4; also elsewhere on the board
/FRONT_EXT_R_SDA: J14.2; also elsewhere on the board
/FRONT_INT_L_SCL: J9.4; also elsewhere on the board
/FRONT_INT_L_SDA: J9.2; also elsewhere on the board
/FRONT_INT_R_SCL: J11.4; also elsewhere on the board
/FRONT_INT_R_SDA: J11.2; also elsewhere on the board
/SCL_SENSE: J15.4, J16.4, J17.4; also elsewhere on the board
/SDA_SENSE: J15.2, J16.2, J17.2; also elsewhere on the board
GND: C19.2, C20.2, C21.2, C22.2, C23.2, C24.2, C25.2, C26.2, C27.2, C28.2, C29.2, C30.2, C31.2, C32.2, C33.2, C34.2, C35.2, C36.2, C37.2, C38.2, J7.1, J8.1, J9.1, J10.1, J11.1, J12.1, J14.1, J15.1, J16.1, J17.1; also elsewhere on the board

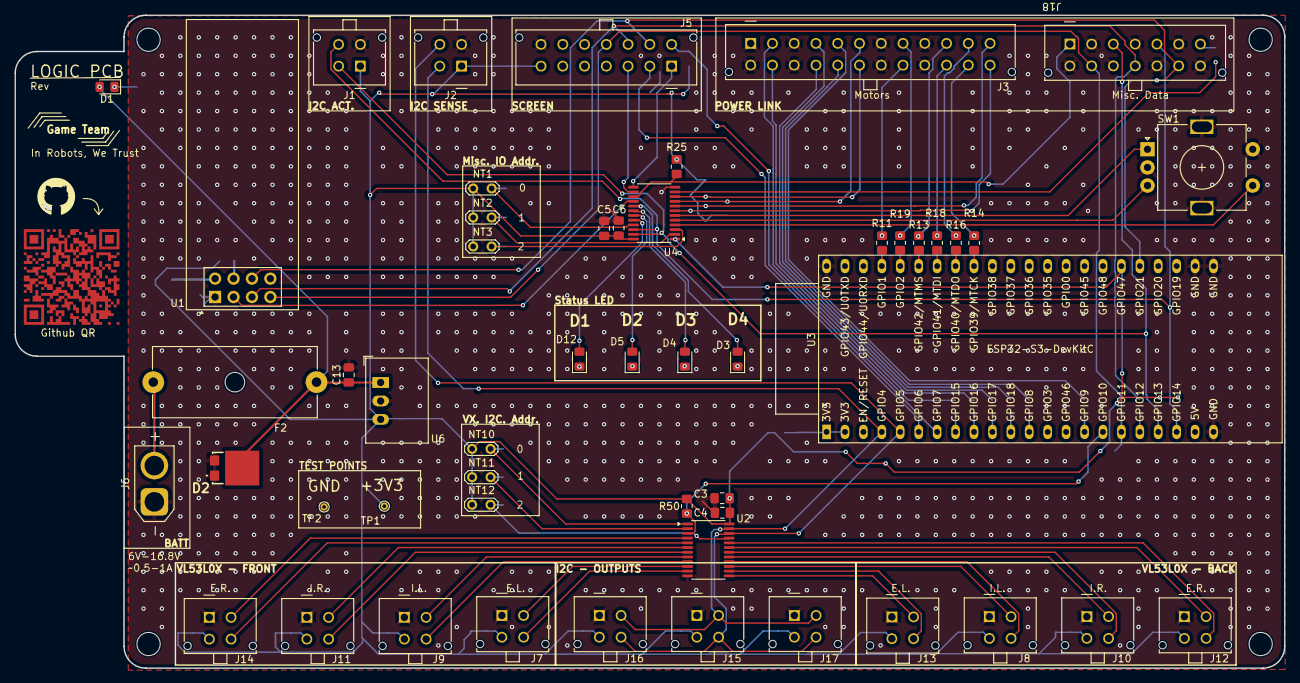
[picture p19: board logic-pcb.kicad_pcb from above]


Board: 2 copper layers, 175.0 x 90.0 mm, 120 parts (64 on the bottom side), 87 nets.

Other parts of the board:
QR*****: Github QR

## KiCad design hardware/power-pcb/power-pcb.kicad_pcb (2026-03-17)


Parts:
C1: 2200u_LowZ; CP_Radial_D16.0mm_P7.50mm; MPN EEUFR1V222
C2, C19, C20, C21, C22, C23: 100n; C_0805_2012Metric_Pad1.18x1.45mm_HandSolder; MPN CL21B104KBCNNND
C3, C4, C18: 10u; C_0805_2012Metric_Pad1.18x1.45mm_HandSolder; MPN CL21A106KBYQNNE
D1: SMCJ18A; D_SMB-SMC_Universal_Handsoldering; MPN SMCJ18A-E3/9AT
D2: 0805_Green; LED_0805_2012Metric_Pad1.15x1.40mm_HandSolder; MPN APA2106ZGCK
F1: 40A; Fuseholder_Cylinder-5x20mm_Schurter_0031_8201_Horizontal_Op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
FB1: BLM21PG331SN1D; L_0805_2012Metric_Pad1.05x1.20mm_HandSolder; MPN BLM21PG331SN1D
H1, H2, H3, H4: MountingHole; MountingHole_3.2mm_M3
J1: XT60-M-AS; AMASS_XT60-M_1x02_P7.20mm_Vertical
J2, J5, J6, J7: XT30; AMASS_XT30U-M_1x02_P5.0mm_Vertical
J8: JST_XH_5; JST_XH_B5B-XH-AM_1x05_P2.50mm_Vertical; MPN B5B-XH-A-G
J13: MicroFit2x12_Odd_Even; J_Wurth_WR-MPC3_66202421122; MPN 43045-2412
J18: Conn_02x07_Odd_Even; J_Wurth_WR-MPC3_66201421122; MPN 43045-1412
Q1, Q2: SQJ138EP-T1_GE3; PowerPAK_SO-8L_Single_MOS; MPN SQJ138EP-T1_GE3
R1, R16: 10k; R_0805_2012Metric_Pad1.20x1.40mm_HandSolder; MPN CRCW080510K0FKEA
R2, R41: 100k; R_0805_2012Metric_Pad1.20x1.40mm_HandSolder; MPN CRCW0805100KFKEA
R3: 8.06M; R_0805_2012Metric_Pad1.20x1.40mm_HandSolder; MPN RC0805FR-078M06L
R4: 66.5k; R_0805_2012Metric_Pad1.20x1.40mm_HandSolder; MPN CRCW080566K5FKEA
R5: 232k; R_0805_2012Metric_Pad1.20x1.40mm_HandSolder; MPN CRCW0805232KFKEA
R6: 150; R_0805_2012Metric_Pad1.20x1.40mm_HandSolder; MPN CRCW0805150RFKEA
R7: 33R; R_0805_2012Metric_Pad1.20x1.40mm_HandSolder; MPN CRCW080533R0FKEA
R12: 1k; R_0805_2012Metric_Pad1.20x1.40mm_HandSolder; MPN CRCW08051K00FKEA
R39: 16.9k; R_0805_2012Metric_Pad1.20x1.40mm_HandSolder; MPN CRCW080516K9FKEA
R40: 59.0k; R_0805_2012Metric_Pad1.20x1.40mm_HandSolder; MPN CRCW080559K0FKEA
R42, R47: 24.9k; R_0805_2012Metric_Pad1.20x1.40mm_HandSolder; MPN CRCW080524K9FKEA
R46: 143k; R_0805_2012Metric_Pad1.20x1.40mm_HandSolder; MPN CRCW0805143KFKEA
R48, R49: 24.9K; R_0805_2012Metric_Pad1.20x1.40mm_HandSolder; MPN CRCW080524K9FKEA
TP1, TP2, TP3: TestPoint; TestPoint_THTPad_D1.0mm_Drill0.5mm
U1: BTS50010-1TAE; TO-263-7_TabPin4; MPN BTS500101TAEATMA1
U2: LTC4365TS8; TSOT-23-8_HandSoldering; MPN LTC4365ITS8-1#TRMPBF
U3: R-78E3.3-1.0; Converter_DCDC_RECOM_R-78E-0.5_THT; MPN R-78E3.3-1.0
U8: ADS1015IDGS; TSSOP-10_3x3mm_P0.5mm; MPN ADS1015IDGS

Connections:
+3V3: C4.1, FB1.1, R16.1, TP3.1, U3.3 (OUT); also elsewhere on the board
+BATT: C3.1, D2.2 (A), J5.2, J6.2, J7.2, TP1.1, U1.5 (OUT), U1.6 (OUT), U1.7 (OUT), U3.1 (IN); also elsewhere on the board
/BATT_C1: J8.4, R39.1
/BATT_C1_D: C20.2, R39.2, R42.1, U8.4 (AIN0)
/BATT_C2: J8.3, R40.1
/BATT_C2_D: C21.2, R40.2, R47.1, U8.5 (AIN1)
/BATT_C3: J8.2, R41.1
/BATT_C3_D: C22.2, R41.2, R48.1, U8.7 (AIN3)
/BATT_C4: J8.1, R46.1
/BATT_C4_D: C23.2, R46.2, R49.1, U8.6 (AIN2)
/BL.CS: J13.20; also elsewhere on the board
/BL.D1: J13.19; also elsewhere on the board
/BL.DIR: J13.21; also elsewhere on the board
/BL.STEP: J13.23; also elsewhere on the board
/BR.CS: J13.8; also elsewhere on the board
/BR.D1: J13.7; also elsewhere on the board
/BR.DIR: J13.9; also elsewhere on the board
/BR.STEP: J13.11; also elsewhere on the board
/FL.CS: J13.2; also elsewhere on the board
/FL.D1: J13.1; also elsewhere on the board
/FL.DIR: J13.5; also elsewhere on the board
/FL.STEP: J13.3; also elsewhere on the board
/FR.CS: J13.14; also elsewhere on the board
/FR.D1: J13.13; also elsewhere on the board
/FR.DIR: J13.17; also elsewhere on the board
/FR.STEP: J13.15; also elsewhere on the board
/MISO: R7.1; also elsewhere on the board
/MOSI: J18.6; also elsewhere on the board
/PROP_EN: J18.14, R16.2; also elsewhere on the board
/RVP_BAU: C2.2, D1.1 (K), F1.2, Q1.1 (D), R2.1, R3.1, U2.1 (Vin)
/SCK: J18.4; also elsewhere on the board
/SCL_ACTUATION: J18.12, U8.10 (SCL)
/SDA_ACTUATION: J18.10, U8.9 (SDA)
/UOV_BAU: C1.1, J2.2, Q2.1 (D), U1.4 (Vbb), U2.7 (Vout)
/UOV_FAULT: J18.8, U2.6 (~FAULT)
GND: C1.2, C2.1, C3.2, C4.2, C18.1, C19.2, C20.1, C21.1, C22.1, C23.1, D1.2 (A), J1.1, J5.1, J6.1, J7.1, J13.4, J13.6, J13.10, J13.12, J13.16, J13.18, J13.22, J13.24, J18.1, J18.3, J18.5, J18.7, J18.9, J18.11, J18.13, R5.1, R6.2, R12.2, R42.2, R47.2, R48.2, R49.2, TP2.1, U2.4 (GND), U3.2 (GND), U8.1 (ADDR), U8.3 (GND); also elsewhere on the board
unnamed: D2.1 (K), R12.1
unnamed: F1.1, J1.2
unnamed: J2.1, R1.1
unnamed: J18.2, R7.2
unnamed: Q1.2 (G), Q2.2 (G), U2.8 (GATE)
unnamed: Q1.3 (S), Q2.3 (S)
unnamed: R6.1, U1.1 (GND)
unnamed: R1.2, U1.2 (IN)
unnamed: R4.2, R5.2, U2.3 (OV)
unnamed: R3.2, R4.1, U2.2 (UV)
unnamed: R2.2, U2.5 (~SHDN)
unnamed: C18.2, C19.1, FB1.2, U8.8 (VDD)

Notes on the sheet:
200W reg - 6V
Power indicator
Prop EN pullup
BAU
Logic PWR
Batt dividers
Cell monitoring
BATT INPUT
Logic/motors
Under/overVoltage protection
200W reg - 6V
TVS
Propulsion Motors
3.3 v
BATT monitoring
Servo regulators


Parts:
C5: 330u_LowZ; CP_Radial_D10.0mm_P5.00mm; MPN EEUFR1V331U
C6, C7: 100n; C_0805_2012Metric_Pad1.18x1.45mm_HandSolder; MPN CL21B104KBCNNND
J9: Molex_MicroFit-3.0_4x1; J_Wurth_WR-MPC3_66200421122; MPN 66200421122
R13, R14, R15: 10k; R_0805_2012Metric_Pad1.20x1.40mm_HandSolder; MPN CRCW080510K0FKEA
U4: BTT_TMC5160T_Pro

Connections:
+3V3: C7.1, R13.1, U4.15 (VIO); also elsewhere on the board
+BATT: C5.1, C6.1, U4.9 (VM); also elsewhere on the board
/BL.CS: R13.2, U4.4 (CS); also elsewhere on the board
/BL.D1: U4.18 (DIAG1); also elsewhere on the board
/BL.DIR: R15.2, U4.8 (DIR); also elsewhere on the board
/BL.STEP: R14.2, U4.7 (STEP); also elsewhere on the board
/MISO: U4.5 (MISO); also elsewhere on the board
/MOSI: U4.2 (MOSI); also elsewhere on the board
/Motor_BL/MA: J9.4, U4.11 (A2)
/Motor_BL/MB: J9.2, U4.12 (A1)
/Motor_BL/MC: J9.1, U4.13 (B2)
/Motor_BL/MD: J9.3, U4.14 (B1)
/PROP_EN: U4.1 (~EN); also elsewhere on the board
/SCK: U4.3 (SCK); also elsewhere on the board
GND: C5.2, C6.2, C7.2, R14.1, R15.1, U4.10 (GND), U4.16 (GND); also elsewhere on the board

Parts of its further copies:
C8, C11, C14: 330u_LowZ; CP_Radial_D10.0mm_P5.00mm; MPN EEUFR1V331U
C9, C10, C12, C13, C15, C16: 100n; C_0805_2012Metric_Pad1.18x1.45mm_HandSolder; MPN CL21B104KBCNNND
J10, J11, J12: Molex_MicroFit-3.0_4x1; J_Wurth_WR-MPC3_66200421122; MPN 66200421122
R17, R18, R19, R21, R22, R23, R25, R26, R27: 10k; R_0805_2012Metric_Pad1.20x1.40mm_HandSolder; MPN CRCW080510K0FKEA
U5, U6, U7: BTT_TMC5160T_Pro

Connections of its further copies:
+3V3: C10.1, C13.1, C16.1, R17.1, R21.1, R25.1, U5.15 (VIO), U6.15 (VIO), U7.15 (VIO); also elsewhere on the board
+BATT: C8.1, C9.1, C11.1, C12.1, C14.1, C15.1, U5.9 (VM), U6.9 (VM), U7.9 (VM); also elsewhere on the board
/BR.CS: R17.2, U5.4 (CS); also elsewhere on the board
/BR.D1: U5.18 (DIAG1); also elsewhere on the board
/BR.DIR: R19.2, U5.8 (DIR); also elsewhere on the board
/BR.STEP: R18.2, U5.7 (STEP); also elsewhere on the board
/FL.CS: R21.2, U6.4 (CS); also elsewhere on the board
/FL.D1: U6.18 (DIAG1); also elsewhere on the board
/FL.DIR: R23.2, U6.8 (DIR); also elsewhere on the board
/FL.STEP: R22.2, U6.7 (STEP); also elsewhere on the board
/FR.CS: R25.2, U7.4 (CS); also elsewhere on the board
/FR.D1: U7.18 (DIAG1); also elsewhere on the board
/FR.DIR: R27.2, U7.8 (DIR); also elsewhere on the board
/FR.STEP: R26.2, U7.7 (STEP); also elsewhere on the board
/MISO: U5.5 (MISO), U6.5 (MISO), U7.5 (MISO); also elsewhere on the board
/MOSI: U5.2 (MOSI), U6.2 (MOSI), U7.2 (MOSI); also elsewhere on the board
/Motor_BR/MA: J10.4, U5.11 (A2)
/Motor_BR/MB: J10.2, U5.12 (A1)
/Motor_BR/MC: J10.1, U5.13 (B2)
/Motor_BR/MD: J10.3, U5.14 (B1)
/Motor_FL1/MA: J11.4, U6.11 (A2)
/Motor_FL1/MB: J11.2, U6.12 (A1)
/Motor_FL1/MC: J11.1, U6.13 (B2)
/Motor_FL1/MD: J11.3, U6.14 (B1)
/Motor_FR/MA: J12.4, U7.11 (A2)
/Motor_FR/MB: J12.2, U7.12 (A1)
/Motor_FR/MC: J12.1, U7.13 (B2)
/Motor_FR/MD: J12.3, U7.14 (B1)
/PROP_EN: U5.1 (~EN), U6.1 (~EN), U7.1 (~EN); also elsewhere on the board
/SCK: U5.3 (SCK), U6.3 (SCK), U7.3 (SCK); also elsewhere on the board
GND: C8.2, C9.2, C10.2, C11.2, C12.2, C13.2, C14.2, C15.2, C16.2, R18.1, R19.1, R22.1, R23.1, R26.1, R27.1, U5.10 (GND), U5.16 (GND), U6.10 (GND), U6.16 (GND), U7.10 (GND), U7.16 (GND); also elsewhere on the board



Board: 2 copper layers, 165.0 x 48.0 mm, 85 parts (31 on the bottom side), 64 nets.

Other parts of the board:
QR*****: Github QR

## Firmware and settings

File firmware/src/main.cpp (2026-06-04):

#include <Arduino.h>
#include <SPI.h>

#include <freertos/FreeRTOS.h>
#include <freertos/queue.h>
#include <remote.h>
#include <ioexpander.h>
#include <pwm-controller.h>
#include <buses.h>
#include <movers.h>
#include <i2cexpander.h>
#include <queues.h>
#include <tasks.h>
#include <state.h>
#include <battery.h>
#include <color_sensors.h>
#include <Logger.h>
#include <screen.h>
#include <actions_helpers.h>
#include <encoder.h>

namespace robot {}

void setup() {
    // FORCE global 'SPI' instance to become an HSPI object inside existing RAM.
    // This allows TFT_eSPI, TMCStepper, RF24 etc. (which all hardcode "SPI")
    // to seamlessly share the single HSPI hardware seamlessly.
    SPI.end();
    SPI.~SPIClass();
    new (&SPI) SPIClass(HSPI);

    delay(1000); // Allow time for Serial to initialize
    
    robot::logger::setup();
    robot::queues::begin();  // Initialize queues BEFORE first logger call
    
    info("main", "Setup started");
    
    robot::state::begin();
    robot::buses::begin();
    robot::ioexpander::begin();
    robot::screen::begin();
    robot::movers::begin();
    robot::pwmcontroller::begin();
    robot::remote::connect();
    robot::i2cexpander::begin();
    robot::battery::begin();
    robot::color_sensors::begin();
    robot::encoder::begin();

    robot::tasks::begin();
    robot::encoder::begin();

    // enable movers
    IOExpanderCommand cmd{};
    cmd.expander = robot::config::IOExpander::LOGIC;
    cmd.pin = 7;
    cmd.level = false;
    xQueueSend(robot::queues::io_command_queue, &cmd, 0);

    robot::actions::action_helpers::rotate_turner_front(ArmState::IDLE);
    robot::actions::action_helpers::rotate_turner_back(ArmState::IDLE);

    robot::actions::action_helpers::rotate_grabber_front(GrabberState::FOLDED);
    robot::actions::action_helpers::rotate_grabber_back(GrabberState::FOLDED);
}

void loop() {
    vTaskDelay(pdMS_TO_TICKS(10000));
}

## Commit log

2026-03-03 Added power pcb sch + design
    [power-pcb-B_Cu.gbr, power-pcb-B_Mask.gbr, power-pcb-B_Paste.gbr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]
2026-03-03 Update STEP file output path in power-pcb project configuration
    [power-pcb.kicad_pcb]
2026-03-04 Last fix power PCB
    [power-pcb-B_Cu.gbr, power-pcb-B_Mask.gbr, power-pcb-B_Paste.gbr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]
2026-03-04 remove useless pos files
    [power-pcb-bottom.xlsx, power-pcb-top.xlsx]
2026-03-04 Post DRM adjustements and BOM referencing
    [power-pcb-B_Cu.gbr, power-pcb-B_Mask.gbr, power-pcb-B_Paste.gbr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]
2026-03-04 remove fab
    [power-pcb-B_Cu.gbr, power-pcb-B_Mask.gbr, power-pcb-B_Paste.gbr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]
2026-03-04 Change logic connector
    [logic-pcb.kicad_pcb, logic-pcb.kicad_sch, power-pcb.kicad_pcb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]
2026-03-05 Add shunt for current measure
    [logic-pcb.kicad_sch, power-pcb.kicad_pcb, power-pcb.kicad_sch]
2026-03-12 Add first version for kinematic PCB
    [action-side.kicad_sch, arm.kicad_sch, i2c-source.kicad_sch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]
2026-03-15 Adapt Power PCB to logic requirements
    [Sketch5.dxf, action-side.kicad_sch, arm.kicad_sch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]
2026-03-17 fixes pre-prod
    [action-side.kicad_sch, arm.kicad_sch, eurobot-2026-robot-pcb.kicad_pcb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]
2026-03-24 Add initial implementation of robot firmware modules
    - Created libraries for hardware pins, motion drive, radio, remote mapper, storage monitor, system state, task context, and tasks.
    - Implemented motion drive logic for controlling wheel movements using stepper motors.
    - Developed radio communication handling with RF24 for receiving remote commands.
    - Added remote mapping functionality to interpret joystick inputs and button presses.
    - Implemented storage monitoring to manage stock areas for robot operations.
    - Established system state management to track robot status and telemetry.
    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
2026-04-03 Refactor and reorganize robot firmware tasks and types
    - Consolidated task functions into dedicated files for better organization.
    - Introduced new tasks: battery_watch_task, comm_task, control_action_task, control_IO_task, control_PWM_task, move_task, and sense_task.
    - Created a centralized queue management system for handling commands.
    - Updated types for commands, including MotionCommand, IOExpanderCommand, PWMCommand, and I2CExpanderCommand.
    - Added Vec3, Actionnable, and ControlMode types for improved clarity and structure.
    - Refactored existing code to utilize new structures and tasks, enhancing modularity and readability.
    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
2026-04-06 fixes and chasse neige
    [main.cpp]
2026-04-06 add initialization to servos
2026-04-09 Add logging and safety measures and leds and stuff i forgot
2026-04-25 Add screen initialization and update action handling for pumps and angles
2026-04-30 Add UI rendering and encoder watching tasks
    - Implemented `render_ui_task` to handle UI updates at 30 FPS, including status, control mode, team color, remote frequency, and battery percentage.
    - Introduced a log history feature to display recent logs on the UI.
    - Added `watch_encoder` task to monitor encoder position changes and update the global state accordingly.
    - Both tasks utilize FreeRTOS for efficient task management and delay handling.
2026-05-08 Refactor grabber configurations and enhance pump status handling
2026-05-08 Refactor and clean up code across multiple files
    - Updated `config.h` to fix struct closure and formatting.
    - Removed debug print statements from `movers.cpp`.
    - Enhanced `updateLogs` function in `screen.cpp` to accept additional parameters for better log management.
    - Updated function signature in `screen.h` to match changes in `screen.cpp`.
    - Refactored `comm_task.cpp` to improve grabber control logic and removed disabled code.
    - Improved logging messages in `control_action_task.cpp` for clarity.
    - Updated `control_color_task.cpp` and `control_io_task.cpp` to enhance warning messages.
    - Simplified LED control logic in `control_leds.cpp` by sending individual PWM commands directly.
    - Adjust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
    [main.cpp]
2026-05-08 Refactor stocking and turning actions for front and back grabbers
    - Updated GlobalState structure to separate front and back stocking states.
    - Modified action handling in comm_task to differentiate between front and back actions.
    - Implemented new action functions: stock_front, stock_back, turn_front, turn_back, release_front, release_back, turn_two_front, and turn_two_back.
    - Adjusted control_action_task to call the appropriate action functions based on the current state.
    - Enhanced color detection logic in turn actions to handle front and back separately.
    - Added new action helpers for rotating grabbers and toggling pumps for front and back.
2026-05-10 Refactor pump control logic and update turner rotation handling for improved functionality
2026-05-13 Refactor pump control and turner rotation logic for improved functionality and clarity
2026-06-04 Refactor grabber and turner actions; update motion parameters
    - Updated `turn_two_back` and `turn_two_front` actions to streamline color sensor checks and pump control logic.
    - Introduced new `GrabberState` enum to manage front and back grabber states more effectively.
    - Added functions to set grabber states in the global state.
    - Adjusted motion parameters in `config.h` for improved performance.
    - Enhanced `applyWheelCommand` to prevent unnecessary movements when speed commands are zero.
    - Cleaned up unused code in `move_task` to improve readability.
    - Updated main setup to initialize grabber states using the new enum.
    [main.cpp]
2026-06-10 Refactor action helpers and tasks for improved functionality; update motion parameters and add status LED task
